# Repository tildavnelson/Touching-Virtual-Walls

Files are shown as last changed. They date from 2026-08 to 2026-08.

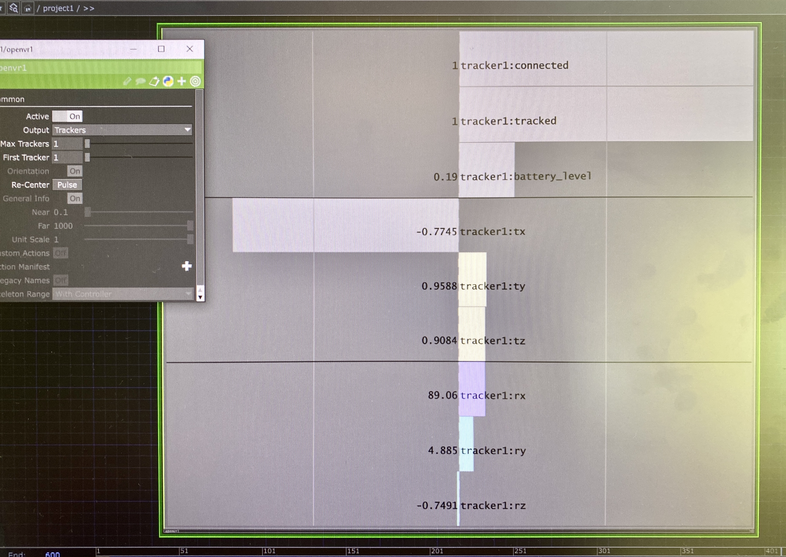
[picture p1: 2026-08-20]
Prototype 2 - VIVE/TouchDesigner/IMG_5856.jpeg

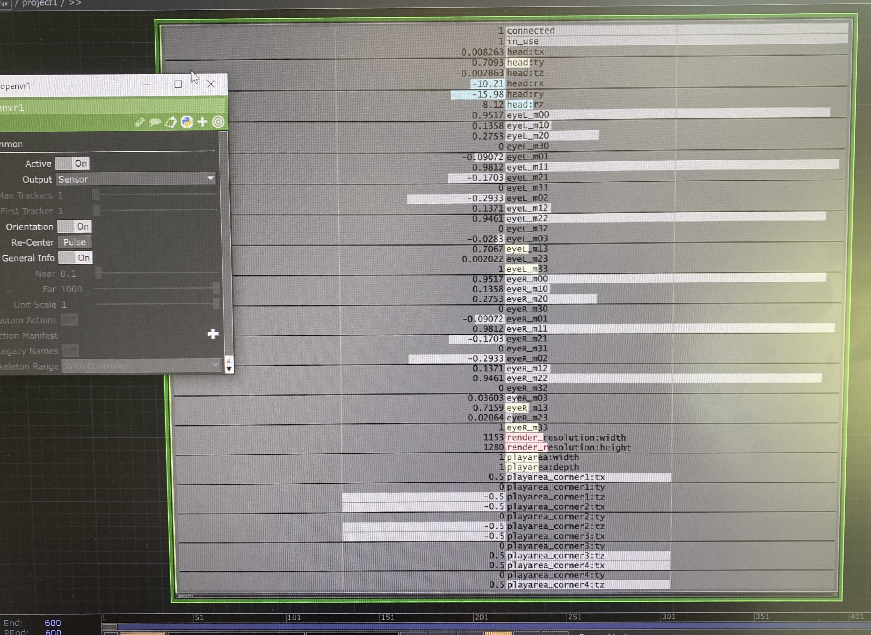
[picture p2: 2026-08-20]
Prototype 2 - VIVE/TouchDesigner/IMG_5855.jpeg

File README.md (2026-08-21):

# Touching Virtual Walls

A handheld kinetic object that traces invisible virtual walls through movement. A performer carries the object; its position and orientation are tracked; a virtual counterpart in TouchDesigner computes how four servo-driven sticks should open to trace the planes of the virtual walls, and sends those angles back to the object in real time.

The object senses its pose, publishes it to an MQTT broker, and TouchDesigner mirrors it in a virtual scene, calculates each stick's angle against the virtual walls, and publishes the angles back for the ESP32 to drive the servos — a closed loop between the physical object and its virtual model.

 **Outdoor UWB demo:** https://youtu.be/p2YoM8ZEzS0

This repository contains the firmware, TouchDesigner project, scripts, 3D models, and setup details needed to reproduce the system. It accompanies the dissertation *Touching Virtual Walls* and documents the first (UWB) prototype in full technical detail.

---

## System overview

Sensors → ESP32 (fusion) → MQTT → TouchDesigner (compute angles) → MQTT → ESP32 → servos

Device data flow-flow chart

1. **Recording the physical.** The ESP32-S3 reads UWB position (DWM1001C) and IMU orientation (BNO055), rejects implausible readings, and fuses position through per-axis Kalman filters.
2. **Physical puppeteering the virtual.** The ESP32 publishes the fused pose as JSON over MQTT.
3. **Mirroring.** TouchDesigner subscribes to the pose, drives an identical virtual object in a 3D scene, and computes each stick's angle against the virtual wall planes.
4. **Virtual puppeteering the physical.** TouchDesigner publishes the four stick angles over MQTT; the ESP32 maps them to PWM and actuates the servos.

The canonical implementation of stages 1, 2 and 4 is `firmware/combined_firmware.ino`; stage 3 lives in the TouchDesigner project. The sections below explain what the code does, with the exact bytes, constants and message formats used.

---

## Hardware

| Component | Role |
|---|---|
| ESP32-S3 Zero | Reads sensors, runs fusion, drives servos, handles Wi-Fi/MQTT |
| DWM1001-DEV (×5) | UWB tracking — 1 tag on the object, 4 anchors in the space |
| BNO055 | 9-axis IMU — orientation |
| PCA9685 | 16-channel PWM driver for the servos |
| SG92R (×4) | Micro servos actuating the four sticks |
| Power | 5 V bank for logic; 4×AA (6 V) for servos; common ground |

**Wiring**

skematics uwb drawio

- I²C (BNO055 at `0x28` + PCA9685 at `0x40`): SDA = GPIO8, SCL = GPIO9 (`Wire.begin(8, 9)`)
- UART to the UWB tag: RX = GPIO44, TX = GPIO43, 115200 baud, 8N1 (`DWM.begin(115200, SERIAL_8N1, 44, 43)`)
- Servo channels on the PCA9685: N = 0, E = 3, S = 2, W = 1
- A common ground across both power sources is essential.

The BNO055 is initialised with axis remap `P1` and the external crystal enabled; the PCA9685 runs at 50 Hz.

> The Vive-tracked exhibition prototype (Prototype 2) replaces the UWB/IMU pose feed with a SteamVR CHOP in TouchDesigner; the servo-actuation half of the firmware is unchanged. .



## Firmware (`/firmware`)

`combined_firmware.ino` — runs on the ESP32-S3.

**Before flashing, set credentials and topics at the top** (blank in the repo):

```cpp
const char* ssid         = "YOUR_SSID";
const char* password     = "YOUR_PASSWORD";
const char* mqtt_server  = "YOUR_BROKER_IP";
const char* pose_topic   = "YOUR_POSE_TOPIC";     // object → TouchDesigner
const char* petals_topic = "YOUR_STICKS_TOPIC";   // TouchDesigner → object
```

The main loop runs four things on independent timers: a fusion update every 20 ms, a DWM position request every 100 ms, a pose publish every 100 ms, and continuous MQTT servicing. The sections below correspond one-to-one to the pipeline stages.

### 1. Requesting position from the DWM1001C Dev board

Every 100 ms the ESP32 wakes the DWM1001 and asks for a position report over UART:

write 0xFF // wake byte — brings the DWM1001C out of low-power sleep
delay 10 ms
write 0x0C 0x00 // "get location" request

Incoming bytes are buffered (up to 256 bytes), and the buffer is parsed once it has had time to arrive (80 ms after the request). The DWM1001C replies with a **TLV (Type–Length–Value)** packet.

### 2. Parsing the TLV packet

The parser scans the buffer for the position record, identified by type byte `0x41` with length `0x0D` (13 bytes):

- **Position** — `x, y, z` as signed 32-bit little-endian integers in **millimetres**, followed by a **position quality factor** `qf` (0–100).
- **Per-anchor distances** — introduced by a distance type byte (`0x49` or `0x48`) and a count, then one record per anchor. Each record carries the anchor **address** (2 bytes), the **raw distance** in millimetres (4 bytes) and a **distance quality factor** (1 byte). Up to 15 anchors are read (`MAX_ANCHORS`).

The two distance types differ only in record stride, so both layouts are handled explicitly.

**Sanity gate.** A reading is only accepted if it falls inside the expected room volume — roughly `x ∈ (−5, 15) m`, `y ∈ (−5, 15) m`, `z ∈ (−5, 10) m`. Anything outside this is discarded rather than fused, which rejects gross multilateration errors before they reach the filter.

### 3. Reading orientation (BNO055)

In parallel, every 20 ms the ESP32 reads the BNO055 over I²C, taking the fused **quaternion** (`qw, qx, qy, qz`), the **Euler angles** (heading, pitch, roll in degrees), and the **calibration status** (`sys, gyro, accel, mag`, each 0–3). It also reads the linear-acceleration and gyroscope vectors, which drive the stillness detection used by the filter.

### 4. Stabilising: adaptive Kalman fusion

The IMU is precise but drifts; the UWB is stable but jitters. Position is fused through **three independent 1-D Kalman filters** (one per axis), whose noise terms adapt every 20 ms to how the object is moving and to how good the UWB reading is.

**Stillness detection.** A sample counts as "still" when acceleration magnitude < `0.08 m/s²` **and** gyroscope magnitude < `3.0 °/s`. A vote counter debounces this over `5` samples so brief spikes don't flip the state.

**Process noise Q** (how much the filter trusts new UWB readings):

- **Still** → `Q` is pinned low (`Q_MIN = 0.002`, and `Q_BASE_Z = 0.004` for the noisier vertical axis) to suppress drift and hold the object steady.
- **Moving** → `Q` scales up with motion magnitude toward `Q_MAX = 0.15`, so the estimate can follow fast movement without lag.

**Measurement noise R** (how much a given UWB reading is trusted) is derived inversely from the position quality factor: high quality drives `R` down toward `R_MIN = 0.3` (trust the reading), low quality drives it up toward `R_MAX = 3.0` (discount it).

| Parameter | Value | Meaning |
|---|---|---|
| `Q_MIN` | 0.002 | Process noise when still (X, Y) |
| `Q_BASE_Z` | 0.004 | Process noise when still (Z) |
| `Q_MAX` | 0.15 | Process noise ceiling when moving |
| `R_MIN` | 0.3 | Measurement noise at best UWB quality |
| `R_MAX` | 3.0 | Measurement noise at worst UWB quality |
| stillness | accel < 0.08 m/s², gyro < 3.0 °/s | held for 5 samples |

The filter outputs a fused position (`raw_x, raw_y, raw_z`) that is steady at rest and responsive in motion.

### 5. Per-anchor calibration

Each DWM1001C chip has a device-specific range bias, largest at short range and flattening beyond ~2.5 m. Because the DWM1001C firmware exposes no direct antenna-delay setting, calibration is applied on the ESP32 instead. Each anchor was placed at known laser-measured distances, the reported values compared against truth, and a linear correction fitted per anchor address:

```cpp
float calibrateAnchorDist(uint16_t addr, float dist_m) {
  switch (addr) {
    case 0x169A: return (dist_m * 0.9733f) + 0.0901f;
    case 0x41A5: return (dist_m * 0.9781f) + 0.0789f;
    case 0x179E: return (dist_m * 0.9634f) + 0.0984f;
    default:     return dist_m;   // uncalibrated anchors pass through unchanged
  }
}
```

The calibrated per-anchor distance is stored and published alongside the raw value, so the correction can be inspected downstream. (Coefficients are specific to these anchors; re-fit for a different set.)

### 6. Publishing the pose (MQTT)

Every 100 ms the ESP32 serialises the fused pose to JSON and publishes it to `pose_topic`. Full schema:

| Field | Meaning |
|---|---|
| `x, y, z` | Fused position (metres) |
| `q` | DWM1001C position quality factor (0–100) |
| `qw, qx, qy, qz` | BNO055 orientation quaternion |
| `heading, pitch, roll` | BNO055 Euler angles (degrees) |
| `cal` | BNO055 system calibration status (0–3) |
| `still` | Stillness state (boolean) |
| `q_xy, r` | Current Kalman process/measurement noise (diagnostic) |
| `t` | Device timestamp (`millis()`) |
| `anchors` | Number of anchors in this reading |
| `anch[]` | Per-anchor array: `addr`, `raw` (mm), `cal` (m), `qf` |

**Worked example** (one real packet):

```json
{"x":3.413633,"y":2.822842,"z":1.115937,"q":60,
 "qw":-0.036926,"qx":-0.117981,"qy":0.213318,"qz":-0.969116,
 "heading":184.3125,"pitch":14.125,"roll":24.625,
 "cal":3,"t":118761,"still":false,"q_xy":0.049244,"r":1.353,
 "anchors":4,
 "anch":[{"addr":6046,"raw":2281,"cal":2.295915,"qf":100},
         {"addr":16805,"raw":3091,"cal":3.102207,"qf":100},
         {"addr":54790,"raw":4492,"cal":4.492,"qf":100},
         {"addr":5786,"raw":4590,"cal":4.557547,"qf":100}]}
```

### 7. Receiving stick angles and driving the servos

The ESP32 subscribes to `petals_topic`. Incoming messages are JSON with keys `"n"`, `"e"`, `"s"`, `"w"`, each an open angle in degrees; the callback calls `setPetal()` for each stick present.

The conversion from open angle to servo pulse happens in two steps:

- **Open angle → servo angle.** The requested open angle is clamped to `0–150°`, then mapped so that `0°` open is the closed rest position and larger values open the petal: `servo_angle = SERVO_CLOSED − open` (with `SERVO_CLOSED = 180°`, `SERVO_OPEN = 30°`).
- **Servo angle → PWM.** The servo angle (`0–180°`) is mapped linearly to the PCA9685 pulse-count range `SERVOMIN = 150 … SERVOMAX = 600` and written to the stick's channel.

| Stick | PCA9685 channel |
|---|---|
| North | 0 |
| East | 3 |
| South | 2 |
| West | 1 |

The four SG92R servos actuate together as the performer moves the tracked prop, producing a real-time kinetic response to the invisible virtual boundaries.

---

## TouchDesigner (`/touchdesigner`)

- `VirtualWall.toe` — the full project
- `scriptangles.py` — per-frame stick-angle calculation (readable copy)
- `mqtt_callback.py` — parses incoming pose JSON to storage

### Mirroring the physical

The MQTT Client DAT subscribes to the pose topic. On receiving the fused pose JSON, the callback parses position and orientation into storage, storing position **only when the quality factor is ≥ 30** and always updating orientation (the IMU is stable). A geometry SOP holds an identical 3D model of the tracked prop and its four servo-driven sticks (north, south, east, west); a transform operator applies the received position and orientation to the whole geometry, placing and rotating the model in the virtual scene.

### Feeling the wall: stick-angle calculation

`scriptangles.py` runs every frame. For each of the four sticks independently, it:

1. Defines the stick's pivot point relative to the tracked object's local coordinate frame.
2. Sweeps every angle from −160° to +160° in 1° steps.
3. For each angle, computes the 3D world position of the stick's tip, accounting for the object's current BNO055-derived rotation.
4. Measures the distance from the tip to each of the three virtual planes.
5. Picks the angle that minimises the distance to the nearest plane.
6. Applies hysteresis — once engaged (distance < 0.10 m), the stick needs 0.15 m of clearance before disengaging — to prevent oscillation.
7. Outputs the final angle, clamped to the servo range.

The angles are written to the `sticksval` table and published to the sticks topic.

### Key structure

- Position is smoothed through DAT-to-CHOP → resample → lag before use.
- The four stick transforms and the body transform read from `sticksval`, **decoupled from the script** to avoid a cook-dependency loop (the loop that otherwise capped the frame rate; see Limitations).

> **Axis note.** UWB is Z-up, TouchDesigner is Y-up; the Y and Z axes are inverted between the DRTLS/Decawave frame and TouchDesigner and must be remapped.

---

## UWB anchor setup (`/setup`)

1. DWM1001-DEV boards ship blank. Flash each with `DWM1001_PANS_R2.0.hex` using SEGGER J-Flash Lite over USB/SWD (this programs the onboard nRF52832): connect → Erase Chip → Program Device.
2. Configure each module as a tag or an anchor in the Decawave DRTLS Manager app (over Bluetooth LE). **One anchor must be set as the network initiator**, or the network will not form.
3. Use 4 anchors (the minimum for stable 3D positioning), two mounted high and two low so height (Z) can be resolved. Keep them off metal.
4. Measure each anchor's XYZ with a laser measurer; Anchor 1 = origin (0,0), Anchor 2 along the X-axis, the rest following in order. Enter the coordinates in the app — these form the reference frame, so any measurement error propagates into every reading.

**Anchor coordinates used:** `[your values]`

---

## 3D models (`/3d-models`)

- `[list your STL / Fusion files]`
- Tag/IMU enclosure modified from *DWM1001 Case (Oxidize Conf Edition)*, Cults3D — `[link]`. Check the licence before redistributing modified files.

---

## MQTT topics

- Pose (object → TouchDesigner): `[your pose topic]`
- Sticks (TouchDesigner → object): `[your sticks topic]`

---

## Media

- **Outdoor UWB recording:** https://youtu.be/p2YoM8ZEzS0
- **BodyLab composited performance:** https://youtu.be/O6ULjkn_9qE

---

## Notes / known limitations

- The TouchDesigner frame rate reached ~10 fps after decoupling the cook loop; a more efficient solution is possible.
- Corners where two walls meet are not fully resolved — the interaction jumps when two walls are close and the script cannot reliably pick the nearest.
- UWB accuracy degrades near metal, near bodies, and below ~2.5 m tag-to-anchor range; it was markedly better outdoors than indoors ([outdoor recording](https://youtu.be/p2YoM8ZEzS0)).

### Planned improvements

- Prototype 2: mount the servos directly on the cog to improve the mechanical linkage.

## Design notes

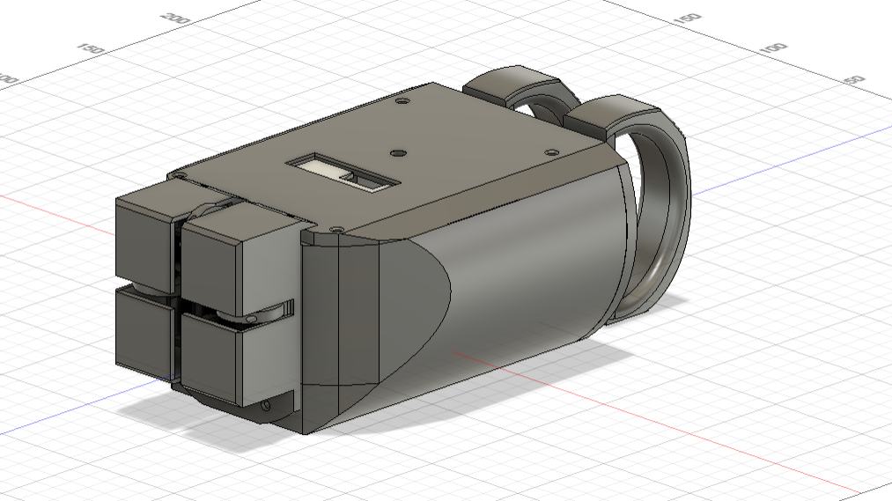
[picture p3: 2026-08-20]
Prototype 1-UWB/images of development/Screenshot 2026-08-19 165014.png

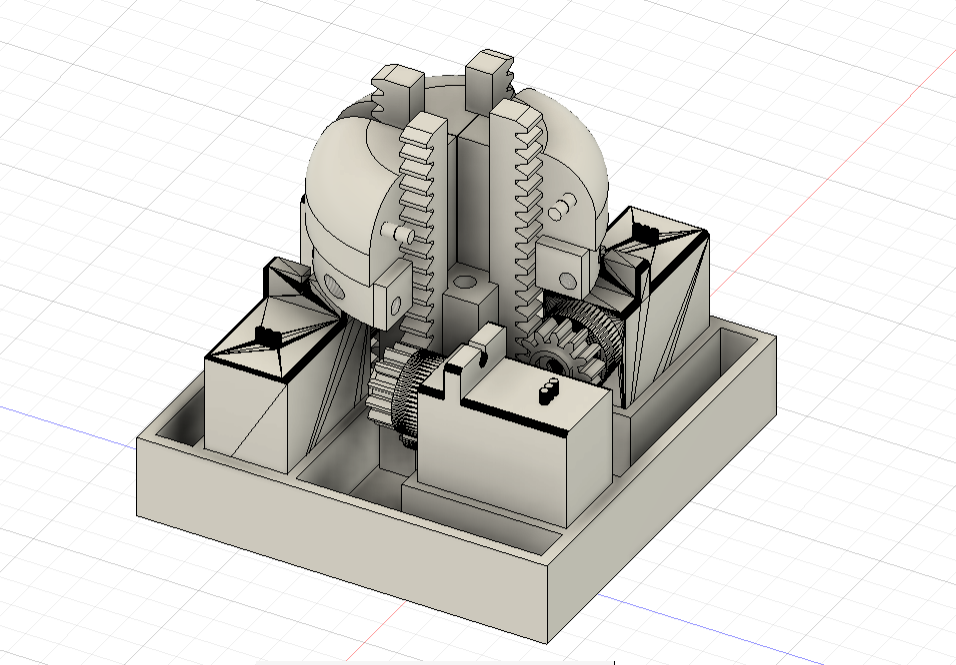
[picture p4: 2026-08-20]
preliminary prototype/preliminary prototype images/Screenshot 2026-08-13 150753.png

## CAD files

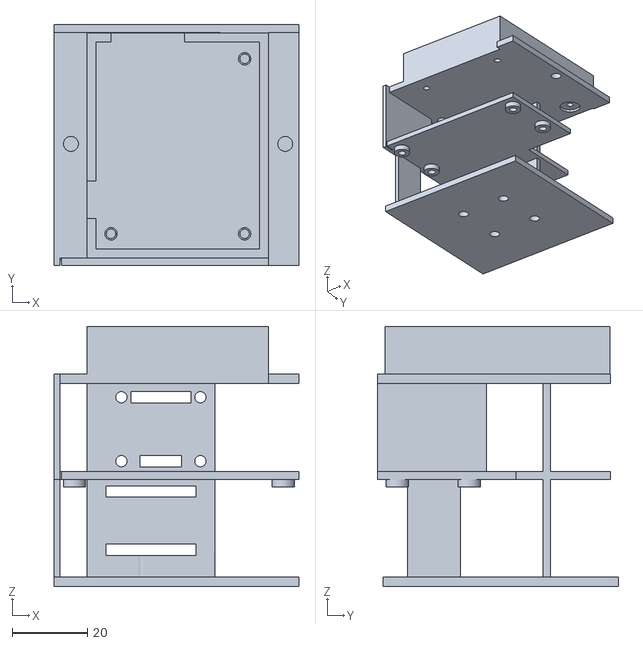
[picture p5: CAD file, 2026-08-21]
2ndversion.stl
65.0 x 64.0 x 69.1

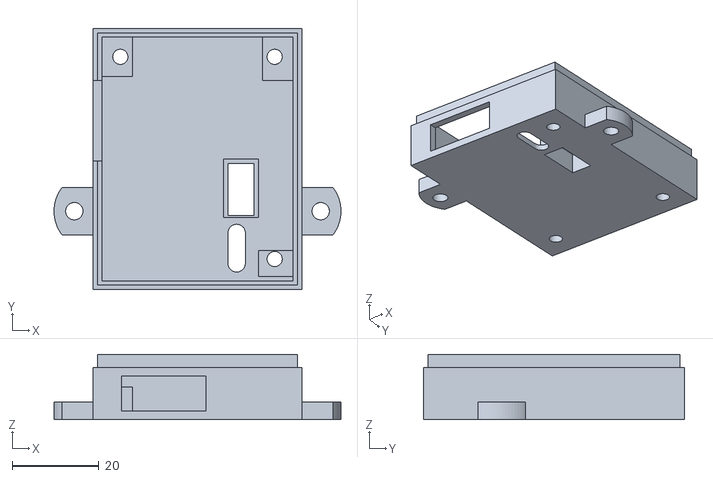
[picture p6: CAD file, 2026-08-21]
3D models for enclosure of anchors/modified anchor boxes.stl
66.0 x 60.0 x 15.0

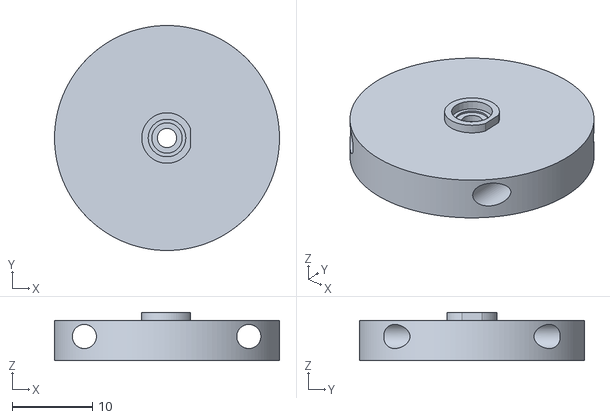
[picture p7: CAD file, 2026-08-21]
2ndcogs.stl
28.0 x 28.0 x 6.00

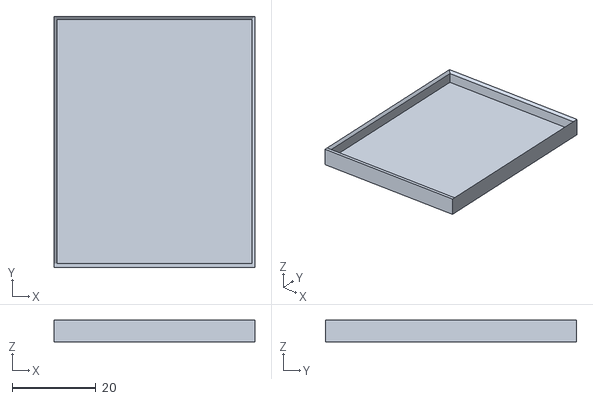
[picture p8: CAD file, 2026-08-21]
3D models for enclosure of anchors/modified Top-box.stl
48.0 x 60.0 x 5.25

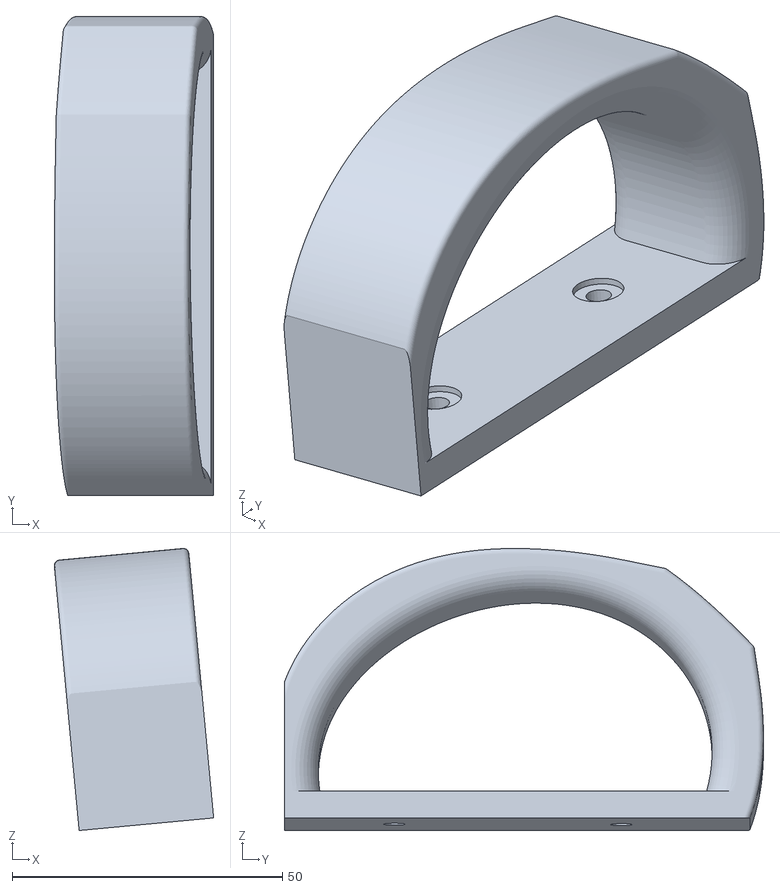
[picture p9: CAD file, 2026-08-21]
Object enclosure & parts/2nd handle.stl
29.5 x 88.6 x 52.2

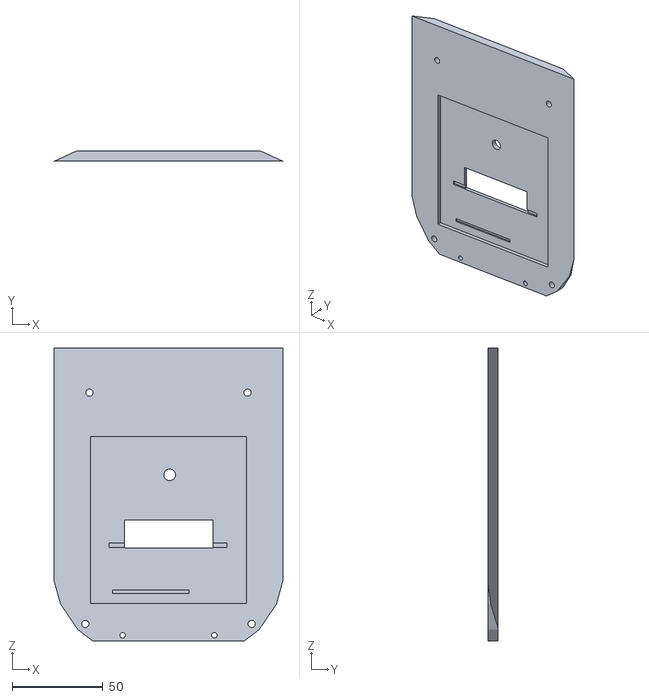
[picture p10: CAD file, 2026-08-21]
2ndlid.stl
125.8 x 5.75 x 161.2

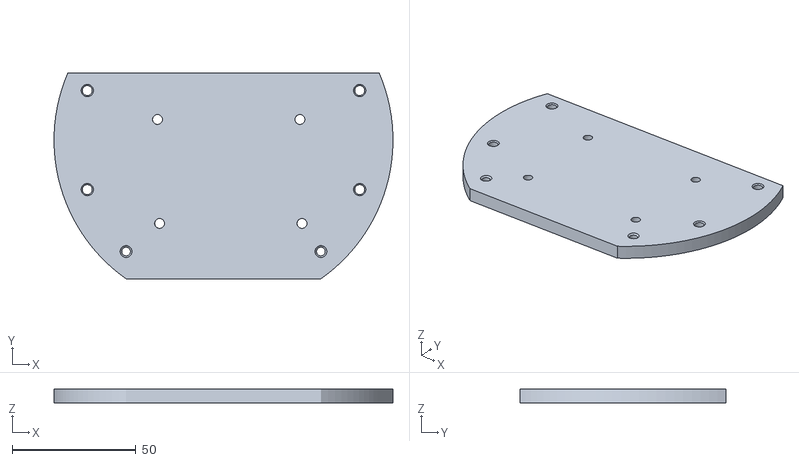
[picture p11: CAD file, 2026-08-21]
Object enclosure & parts/2ndback lid.stl
136.9 x 83.0 x 5.82

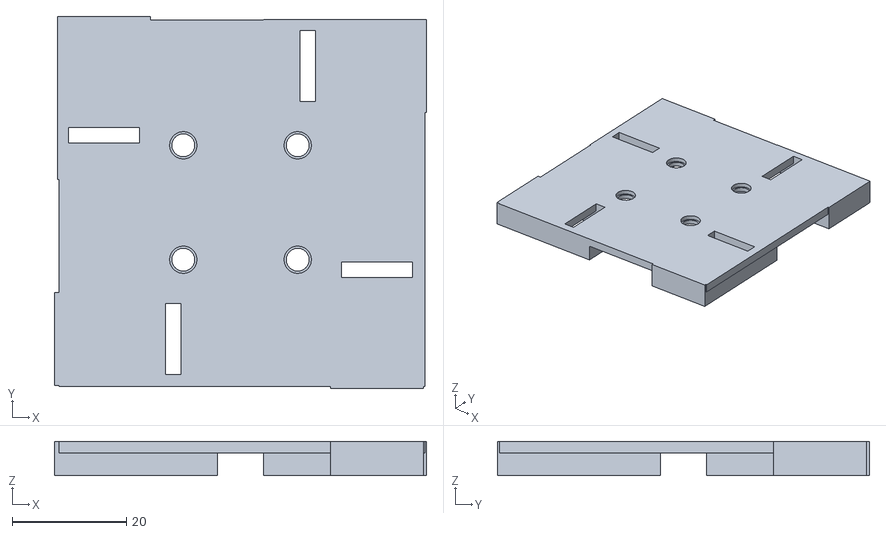
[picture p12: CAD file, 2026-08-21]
2ndservoholder.stl
65.0 x 65.0 x 6.00

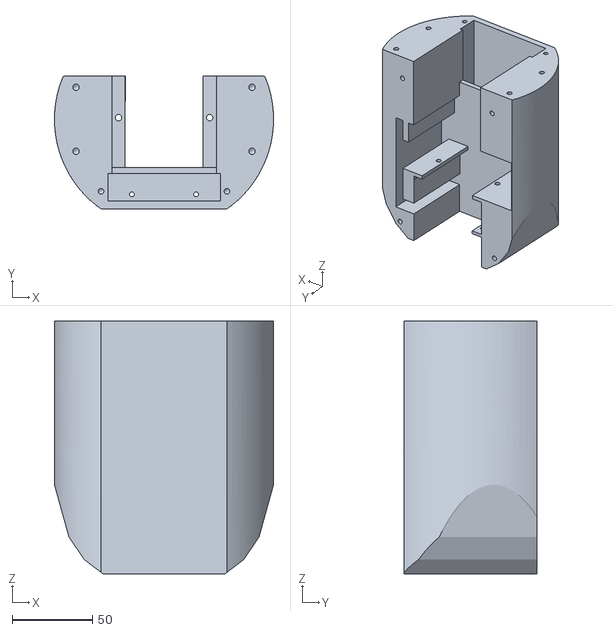
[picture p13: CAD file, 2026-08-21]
Object enclosure & parts/2ndcontainer.stl
136.9 x 83.0 x 158.1

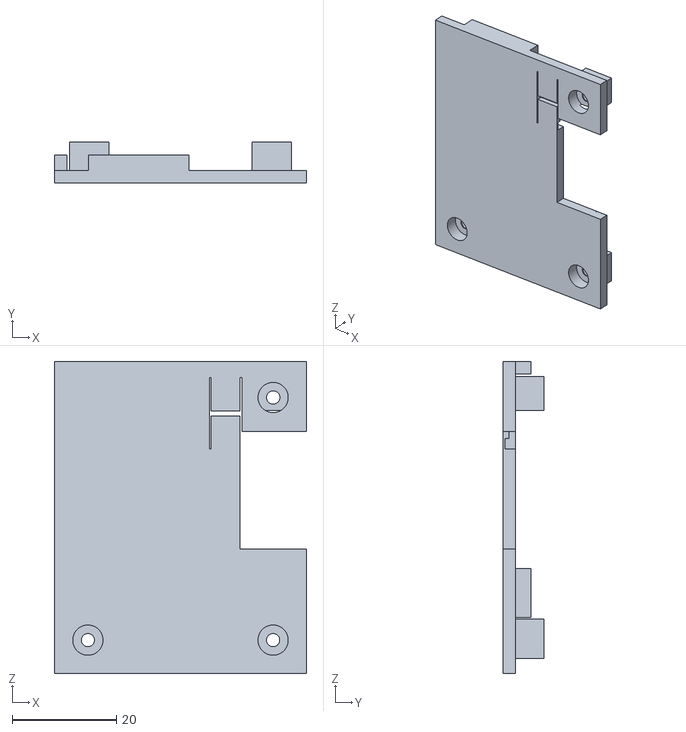
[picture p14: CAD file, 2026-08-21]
2ndversioncover.stl
48.3 x 7.90 x 59.8

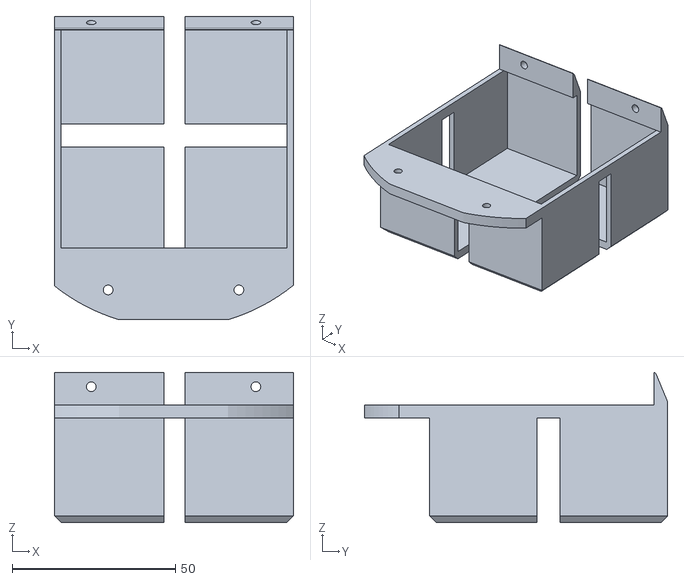
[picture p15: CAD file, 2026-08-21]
Object enclosure & parts/2ndfrontlid.stl
73.3 x 93.0 x 46.0

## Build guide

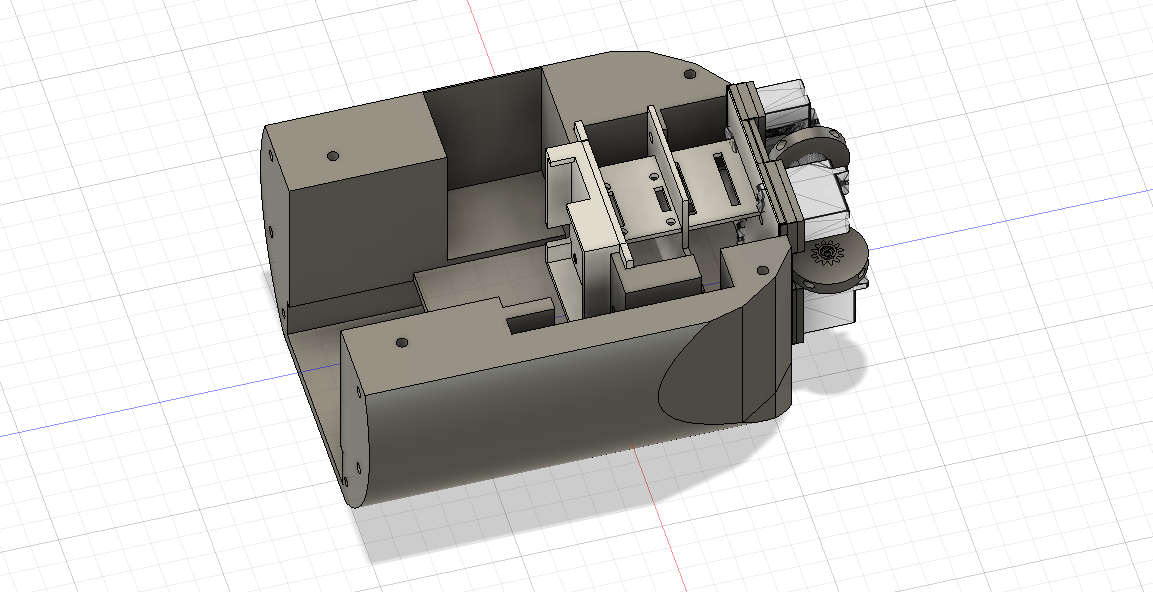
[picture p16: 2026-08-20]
Prototype 1-UWB/wiring.png

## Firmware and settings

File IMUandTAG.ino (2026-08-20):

#include <WiFi.h>
#include <PubSubClient.h>
#include <Wire.h>
#include <Adafruit_Sensor.h>
#include <Adafruit_BNO055.h>
#include <Adafruit_PWMServoDriver.h>
#include <ArduinoJson.h>
#include <HardwareSerial.h>

const char* ssid = "";
const char* password = "";
const char* mqtt_server = "";
const int mqtt_port = 1883;
const char* pose_topic   = "";
const char* petals_topic = "";

Adafruit_BNO055 bno = Adafruit_BNO055(55, 0x28);
Adafruit_PWMServoDriver pwm = Adafruit_PWMServoDriver(0x40);
HardwareSerial DWM(1);

WiFiClient espClient;
PubSubClient client(espClient);

#define SERVOMIN 150
#define SERVOMAX 600
#define SERVO_CLOSED 180
#define SERVO_OPEN   30
#define CH_N 0
#define CH_E 3
#define CH_S 2
#define CH_W 1

unsigned long lastReq = 0;
unsigned long lastPublish = 0;
unsigned long lastFusionUpdate = 0;

const float STILL_ACCEL_THRESH   = 0.08f;
const float STILL_GYRO_THRESH    = 3.0f;
const int   STILL_DEBOUNCE_COUNT = 5;

const float Q_MIN = 0.002f;
const float Q_MAX = 0.15f;
const float Q_BASE_Z = Q_MIN * 2.0f;

const float R_MIN = 0.3f;
const float R_MAX = 3.0f;

float raw_x = 0, raw_y = 0, raw_z = 0;
int pos_q = 0;

#define MAX_ANCHORS 15
struct AnchorReading {
  uint16_t addr;
  uint32_t dist_mm;
  float    dist_cal_m;
  uint8_t  dist_qf;
  bool     valid;
};
AnchorReading anchors[MAX_ANCHORS];
uint8_t anchor_count = 0;

float current_q_xy = Q_MIN;
float current_q_z  = Q_BASE_Z;
float current_r    = 1.0f;

struct Kalman {
  float x, p, q, r, k;
};
Kalman kx = {0, 3, Q_MIN, 1.0, 0};
Kalman ky = {0, 3, Q_MIN, 1.0, 0};
Kalman kz = {0, 3, Q_BASE_Z, 1.0, 0};

float kalmanUpdate(Kalman &k, float measurement, float q_override, float r_override) {
  k.q = q_override;
  k.r = r_override;
  k.p = k.p + k.q;
  k.k = k.p / (k.p + k.r);
  k.x = k.x + k.k * (measurement - k.x);
  k.p = (1 - k.k) * k.p;
  return k.x;
}

bool isStill = false;
int stillVoteCounter = 0;

uint8_t buf[256];
int bufLen = 0;

float calibrateAnchorDist(uint16_t addr, float dist_m) {
  switch (addr) {
    case 0x169A: return (dist_m * 0.9733f) + 0.0901f;
    case 0x41A5: return (dist_m * 0.9781f) + 0.0789f;
    case 0x179E: return (dist_m * 0.9634f) + 0.0984f;
    default:     return dist_m;
  }
}

void setServoAngle(uint8_t channel, int angle) {
  int pulse = map(angle, 0, 180, SERVOMIN, SERVOMAX);
  pwm.setPWM(channel, 0, pulse);
}

void setPetal(uint8_t channel, float openDeg) {
  if (openDeg < 0) openDeg = 0;
  if (openDeg > 150) openDeg = 150;
  int dir = (SERVO_OPEN >= SERVO_CLOSED) ? 1 : -1;
  int angle = SERVO_CLOSED + dir * (int)openDeg;
  setServoAngle(channel, angle);
}

void setup_wifi() {
  Serial.print("Connecting to WiFi...");
  WiFi.begin(ssid, password);
  int attempts = 0;
  while (WiFi.status() != WL_CONNECTED && attempts < 20) {
    delay(500); Serial.print("."); attempts++;
  }
  if (WiFi.status() == WL_CONNECTED) {
    Serial.println("\nWiFi connected: " + WiFi.localIP().toString());
    Serial.println("MAC: " + WiFi.macAddress());
  } else {
    Serial.println("\nWiFi FAILED");
  }
}

void callback(char* topic, byte* payload, unsigned int length) {
  Serial.print("MQTT msg on "); Serial.println(topic);
  StaticJsonDocument<256> doc;
  if (deserializeJson(doc, payload, length)) {
    Serial.println("JSON parse failed");
    return;
  }
  if (doc.containsKey("n")) setPetal(CH_N, doc["n"].as<float>());
  if (doc.containsKey("e")) setPetal(CH_E, doc["e"].as<float>());
  if (doc.containsKey("s")) setPetal(CH_S, doc["s"].as<float>());
  if (doc.containsKey("w")) setPetal(CH_W, doc["w"].as<float>());
}

void reconnect_mqtt() {
  if (client.connected()) return;
  unsigned long now = millis();
  static unsigned long lastAttempt = 0;
  if (now - lastAttempt < 5000) return;
  lastAttempt = now;

  IPAddress resolvedIP;
  if (WiFi.hostByName(mqtt_server, resolvedIP)) {
    Serial.print("Resolved to: ");
    Serial.println(resolvedIP);
  } else {
    Serial.println("DNS resolution FAILED");
  }

  Serial.println("Attempting MQTT connection...");
  if (client.connect("ESP32S3Zero_tilda")) {
    Serial.println("MQTT connected");
    client.subscribe(petals_topic);
  } else {
    Serial.print("MQTT failed, rc="); Serial.println(client.state());
  }
}

void parseTLV(uint8_t* buf, int len) {
  anchor_count = 0;
  for (int i = 0; i < len - 14; i++) {
    if (buf[i] == 0x41 && buf[i+1] == 0x0D) {
      int32_t x = buf[i+2]  | (buf[i+3]<<8)  | (buf[i+4]<<16)  | (buf[i+5]<<24);
      int32_t y = buf[i+6]  | (buf[i+7]<<8)  | (buf[i+8]<<16)  | (buf[i+9]<<24);
      int32_t z = buf[i+10] | (buf[i+11]<<8) | (buf[i+12]<<16) | (buf[i+13]<<24);
      uint8_t q = buf[i+14];

      pos_q = q;

      int cursor = i + 15;
      if (cursor + 2 < len) {
        uint8_t distType = buf[cursor];
        uint8_t cnt = buf[cursor + 2];
        cursor += 3;

        if (cnt > MAX_ANCHORS) cnt = MAX_ANCHORS;

        if (distType == 0x49) {
          for (uint8_t a = 0; a < cnt; a++) {
            if (cursor + 20 > len) break;
            uint16_t addr = buf[cursor] | (buf[cursor+1] << 8);
            cursor += 2;
            uint32_t dist = buf[cursor] | (buf[cursor+1]<<8) | (buf[cursor+2]<<16) | (buf[cursor+3]<<24);
            cursor += 4;
            uint8_t dqf = buf[cursor];
            cursor += 1;
            anchors[a].addr       = addr;
            anchors[a].dist_mm    = dist;
            anchors[a].dist_qf    = dqf;
            anchors[a].valid      = true;
            anchors[a].dist_cal_m = calibrateAnchorDist(addr, dist / 1000.0f);
            cursor += 13;
          }
          anchor_count = cnt;
        } else if (distType == 0x48) {
          for (uint8_t a = 0; a < cnt; a++) {
            if (cursor + 13 > len) break;
            uint16_t addr = buf[cursor] | (buf[cursor+1] << 8);
            cursor += 8;
            uint32_t dist = buf[cursor] | (buf[cursor+1]<<8) | (buf[cursor+2]<<16) | (buf[cursor+3]<<24);
            cursor += 4;
            uint8_t dqf = buf[cursor];
            cursor += 1;
            anchors[a].addr       = addr;
            anchors[a].dist_mm    = dist;
            anchors[a].dist_qf    = dqf;
            anchors[a].valid      = true;
            anchors[a].dist_cal_m = calibrateAnchorDist(addr, dist / 1000.0f);
          }
          anchor_count = cnt;
        }
      }

      float mx = x / 1000.0f;
      float my = y / 1000.0f;
      float mz = z / 1000.0f;

      if (mx > -5.0f && mx < 15.0f &&
          my > -5.0f && my < 15.0f &&
          mz > -5.0f && mz < 10.0f) {
        raw_x = kalmanUpdate(kx, mx, current_q_xy, current_r);
        raw_y = kalmanUpdate(ky, my, current_q_xy, current_r);
        raw_z = kalmanUpdate(kz, mz, current_q_z,  current_r);
      }
    }
  }
}

float qualityToR(uint8_t qf) {
  float frac = qf / 100.0f;
  if (frac < 0) frac = 0;
  if (frac > 1) frac = 1;
  return R_MAX - frac * (R_MAX - R_MIN);
}

float motionToQ(float motionMagnitude, float qMin, float qMax, float motionCeiling) {
  float frac = motionMagnitude / motionCeiling;
  if (frac < 0) frac = 0;
  if (frac > 1) frac = 1;
  return qMin + frac * (qMax - qMin);
}

void updateFusion() {
  imu::Vector<3> linAccel = bno.getVector(Adafruit_BNO055::VECTOR_LINEARACCEL);
  imu::Vector<3> gyro     = bno.getVector(Adafruit_BNO055::VECTOR_GYROSCOPE);

  float accelMag = sqrt(linAccel.x()*linAccel.x() + linAccel.y()*linAccel.y() + linAccel.z()*linAccel.z());
  float gyroMag  = sqrt(gyro.x()*gyro.x() + gyro.y()*gyro.y() + gyro.z()*gyro.z());

  bool sampleLooksStill = (accelMag < STILL_ACCEL_THRESH) && (gyroMag < STILL_GYRO_THRESH);

  if (sampleLooksStill) {
    stillVoteCounter++;
    if (stillVoteCounter > STILL_DEBOUNCE_COUNT) stillVoteCounter = STILL_DEBOUNCE_COUNT;
  } else {
    stillVoteCounter--;
    if (stillVoteCounter < -STILL_DEBOUNCE_COUNT) stillVoteCounter = -STILL_DEBOUNCE_COUNT;
  }

  if (stillVoteCounter >= STILL_DEBOUNCE_COUNT) {
    isStill = true;
  } else if (stillVoteCounter <= -STILL_DEBOUNCE_COUNT) {
    isStill = false;
  }

  if (isStill) {
    current_q_xy = Q_MIN;
    current_q_z  = Q_BASE_Z;
  } else {
    float motionMag = max(accelMag, gyroMag / 50.0f);
    current_q_xy = motionToQ(motionMag, Q_MIN, Q_MAX, 2.0f);
    current_q_z  = motionToQ(motionMag, Q_BASE_Z, Q_MAX, 2.0f);
  }

  current_r = qualityToR((uint8_t)pos_q);
}

void setup() {
  Serial.begin(115200);
  delay(1000);
  Wire.begin(8, 9);
  if (!bno.begin()) {
    Serial.println("BNO055 not found");
  } else {
    bno.setAxisRemap(Adafruit_BNO055::REMAP_CONFIG_P1);
    bno.setAxisSign(Adafruit_BNO055::REMAP_SIGN_P1);
    bno.setExtCrystalUse(true);
    Serial.println("BNO055 ready");
  }
  pwm.begin();
  pwm.setPWMFreq(50);
  setServoAngle(CH_N, SERVO_CLOSED);
  setServoAngle(CH_E, SERVO_CLOSED);
  setServoAngle(CH_S, SERVO_CLOSED);
  setServoAngle(CH_W, SERVO_CLOSED);
  DWM.begin(115200, SERIAL_8N1, 44, 43);
  delay(2000);
  setup_wifi();
  client.setServer(mqtt_server, mqtt_port);
  client.setCallback(callback);
  client.setBufferSize(1024);
}

void loop() {
  if (!client.connected()) reconnect_mqtt();
  client.loop();

  if (millis() - lastFusionUpdate > 20) {
    updateFusion();
    lastFusionUpdate = millis();
  }

  if (millis() - lastReq > 100) {
    DWM.write(0xFF); delay(10);
    uint8_t req[2] = {0x0C, 0x00};
    DWM.write(req, 2);
    lastReq = millis(); bufLen = 0;
  }
  while (DWM.available()) {
    byte b = DWM.read();
    if (bufLen < 256) buf[bufLen++] = b;
  }

  if (bufLen > 0 && millis() - lastReq > 80) {
    parseTLV(buf, bufLen);
    Serial.printf("pos: x=%.2f y=%.2f z=%.2f qf=%d | anchors=%d\n",
      raw_x, raw_y, raw_z, pos_q, anchor_count);

    imu::Quaternion quat = bno.getQuat();
    imu::Vector<3> euler = bno.getVector(Adafruit_BNO055::VECTOR_EULER);
    uint8_t sys, gyro_cal, accel_cal, mag_cal;
    bno.getCalibration(&sys, &gyro_cal, &accel_cal, &mag_cal);
    Serial.printf("imu: h=%.1f p=%.1f r=%.1f | qw=%.3f qx=%.3f qy=%.3f qz=%.3f | cal sys=%d gyro=%d accel=%d mag=%d\n",
      euler.x(), euler.y(), euler.z(),
      quat.w(), quat.x(), quat.y(), quat.z(),
      sys, gyro_cal, accel_cal, mag_cal);

    for (int a = 0; a < anchor_count; a++) {
      Serial.printf("  anchor %d: addr=0x%04X raw=%dmm cal=%.3fm qf=%d\n",
        a, anchors[a].addr, anchors[a].dist_mm, anchors[a].dist_cal_m, anchors[a].dist_qf);
    }
  }

  if (millis() - lastPublish > 100) {
    lastPublish = millis();
    imu::Quaternion quat = bno.getQuat();
    imu::Vector<3> euler = bno.getVector(Adafruit_BNO055::VECTOR_EULER);
    uint8_t sys, gyro, accel, mag;
    bno.getCalibration(&sys, &gyro, &accel, &mag);

    StaticJsonDocument<1024> doc;
    doc["x"]=raw_x; doc["y"]=raw_y; doc["z"]=raw_z; doc["q"]=pos_q;
    doc["qw"]=quat.w(); doc["qx"]=quat.x(); doc["qy"]=quat.y(); doc["qz"]=quat.z();
    doc["heading"]=euler.x(); doc["pitch"]=euler.y(); doc["roll"]=euler.z();
    doc["cal"]=sys; doc["t"]=millis();
    doc["still"]=isStill;
    doc["q_xy"]=current_q_xy; doc["r"]=current_r;
    doc["anchors"]=anchor_count;

    JsonArray anch = doc.createNestedArray("anch");
    for (int a = 0; a < anchor_count; a++) {
      JsonObject o = anch.createNestedObject();
      o["addr"] = anchors[a].addr;
      o["raw"]  = anchors[a].dist_mm;
      o["cal"]  = anchors[a].dist_cal_m;
      o["qf"]   = anchors[a].dist_qf;
    }

    char payload[1024];
    serializeJson(doc, payload);
    client.publish(pose_topic, payload);
  }
}
